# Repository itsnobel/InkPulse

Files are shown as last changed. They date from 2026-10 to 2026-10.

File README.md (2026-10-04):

# 🖊️ InkPulse — High-Speed Ultra-Low-Cost CNC XY Plotter

**InkPulse** is a custom-built, ultra-low-cost, high-speed automated XY-plotter designed to draw vector artwork and render handwritten text with extreme accuracy. Built from scratch without expensive linear bearings, this project pushes the limits of DIY hardware optimization through low-cost 3D printing and custom firmware hacking.

---

## 🌟 Key Features & Engineering Highlights

* **Ultra-Low Cost Engineering:** Replaced expensive LM8UU linear bearings with custom 3D-printed friction-based rod guides, lowering construction costs significantly compared to typical DIY plotters.
* **Firmware Register-Level Pin Remapping:** Custom **GRBL-Servo 0.9i** firmware running at **115200 Baud Rate**, remapped directly at `cpu_map_atmega328p.h` level. Y-axis pins (Step: 4, Dir: 7) were swapped with Z-axis pins (Step: 3, Dir: 6) to drive the pen lift via standard Z-slot G-code commands (`M3`/`M5`).
* **High-Speed Acceleration:** Powered by a 19V 3A DC power supply and GT2 belt-drive system, tuned to achieve up to **10,000 mm/min** maximum feed rate and **500 mm/sec²** acceleration.
* **Electrical Noise Mitigation:** Integrated a 50V 1000µF decoupling capacitor in parallel across the SG90/MG90S servo line to eliminate voltage spikes and prevent Arduino serial disconnects.

---

## 🛠️ Hardware & Components List

| Component | Description |
| :--- | :--- |
| **Controller** | Arduino Uno R3 |
| **Shield** | CNC Shield V3 |
| **Drivers** | A4988 Stepper Drivers (1/16 microstepping) |
|**Motors** | Nema 17 45Ncm stepper motor|
| **Power Supply** | 19V 3A DC Adapter |
| **Pen Lift** | SG90 / MG90S Micro Servo Motor |
| **Drive System** | GT2 Belts & 20-Tooth Pulleys |
| **Structure** | Custom 3D Printed Rod Guides + Smooth Steel Rods |
| **Power Filter**| 1000uF Electrolytic Capacitor |
|**Others**| Cooling fan, holding parts(screw, zip tie) |

---

## 📷 Photos & Video Demonstration

### Project Build & Working Demo
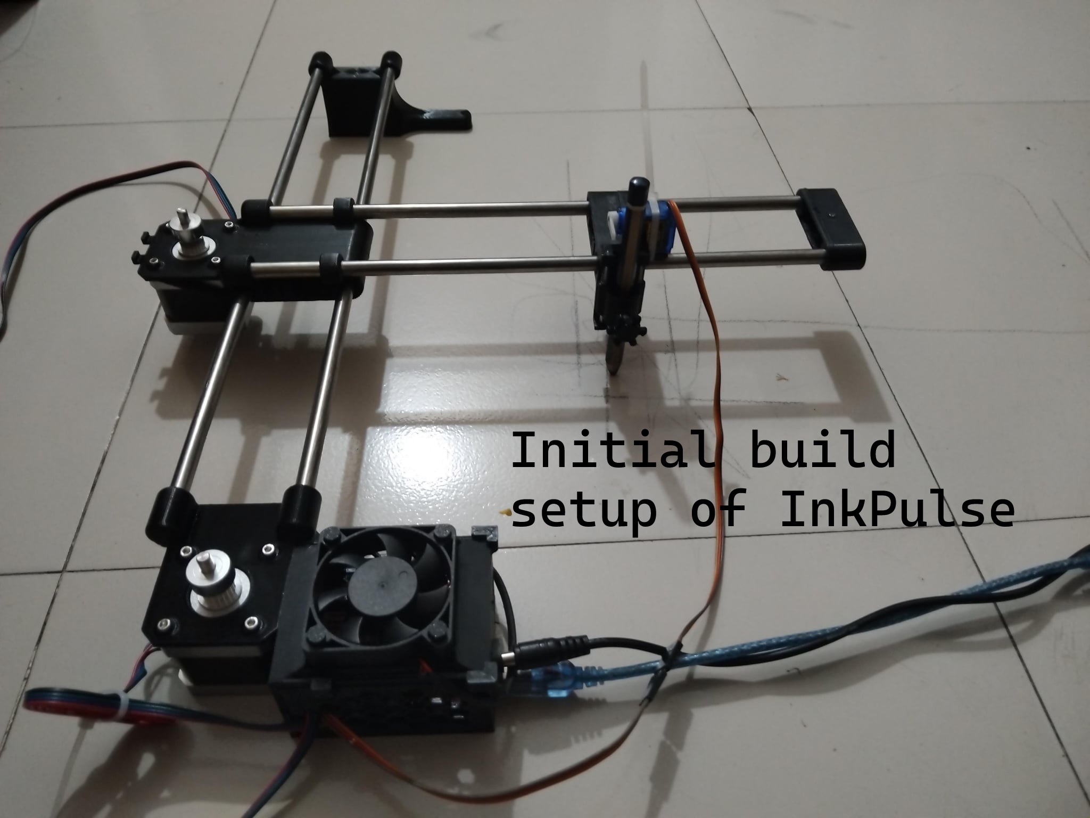
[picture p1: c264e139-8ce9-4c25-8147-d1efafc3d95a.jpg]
InkPulse Build

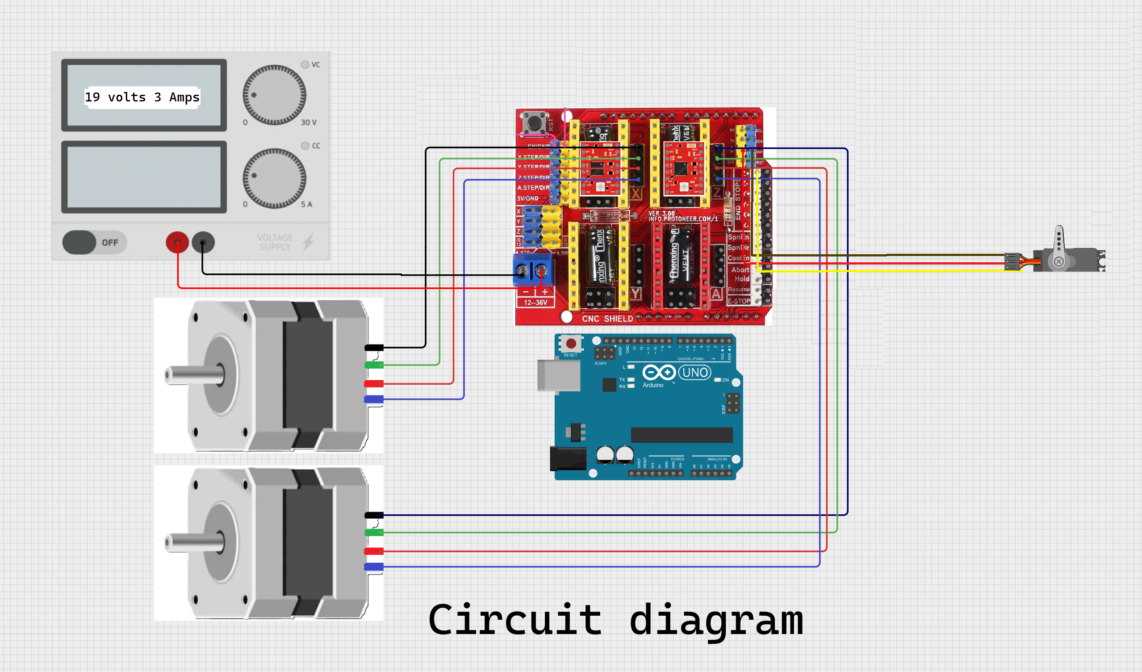
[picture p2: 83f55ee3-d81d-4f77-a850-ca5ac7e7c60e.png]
Hardware Setup

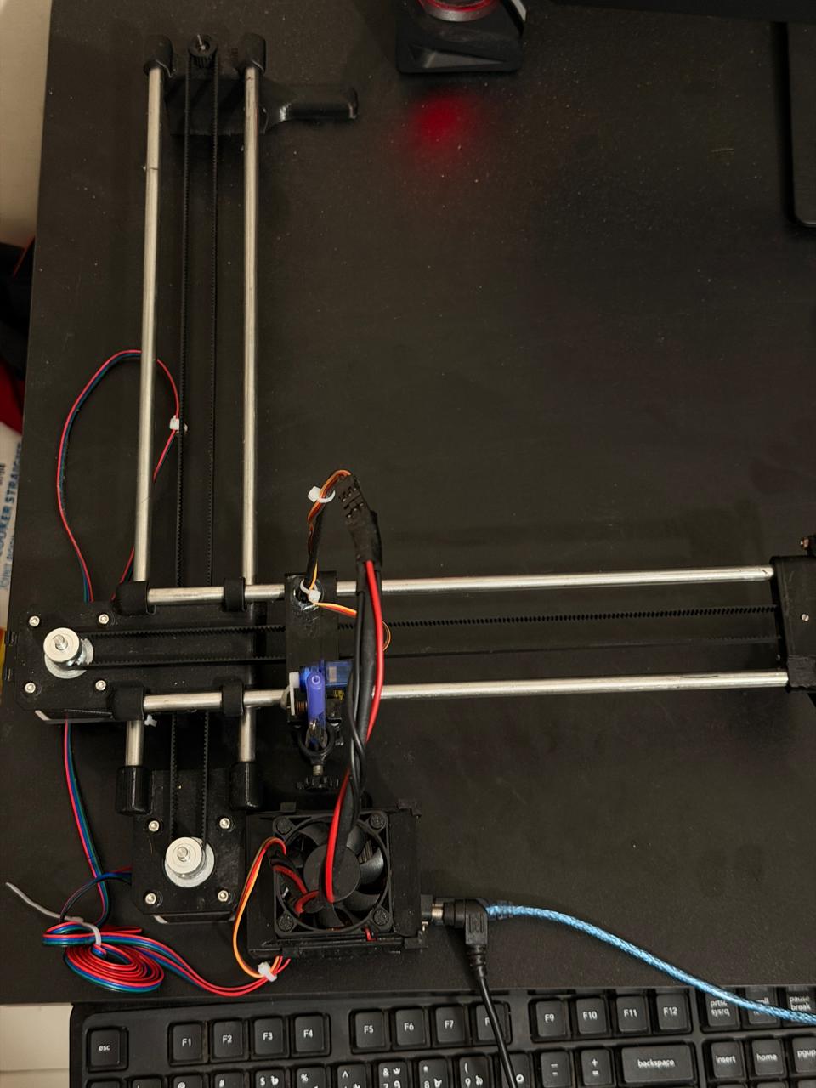
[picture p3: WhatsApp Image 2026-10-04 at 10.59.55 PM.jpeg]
Working Demonstration


🎬 **Watch Video Demo:** [Click here to view the plotter in action](WhatsApp%20Video%202026-10-04%20at%2010.53.54%20PM_squished.mp4)

---

## ⚙️️ Custom GRBL Settings

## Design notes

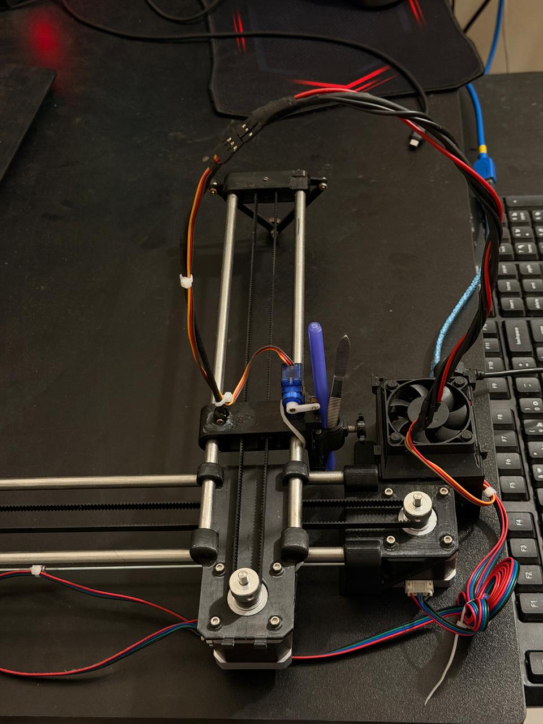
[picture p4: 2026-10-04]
9bd96195-bd8f-48d8-b6e4-d49fcb13c53a.jpg

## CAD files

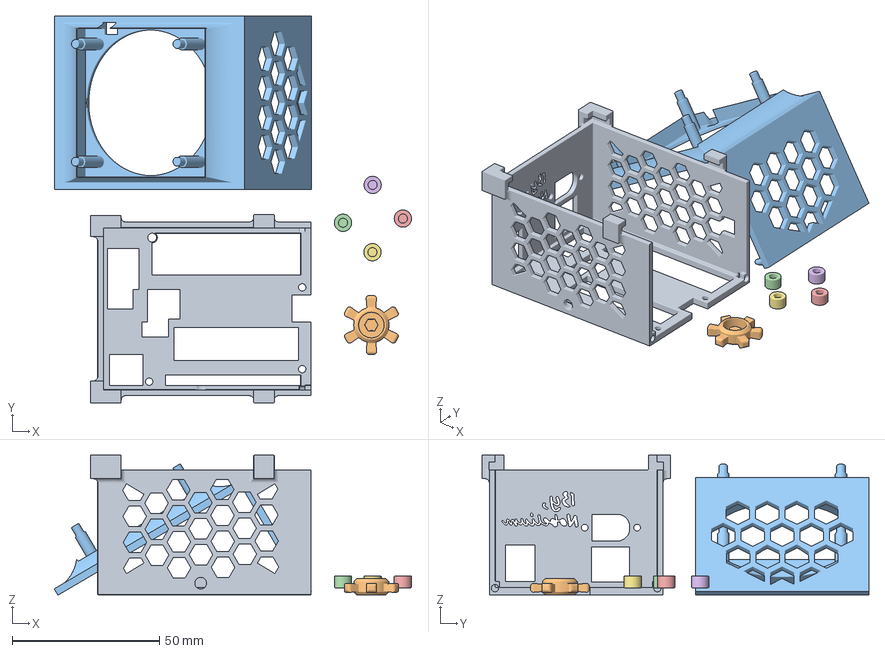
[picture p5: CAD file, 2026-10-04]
Control Unit.3mf
121.4 x 131.5 x 47.5 mm

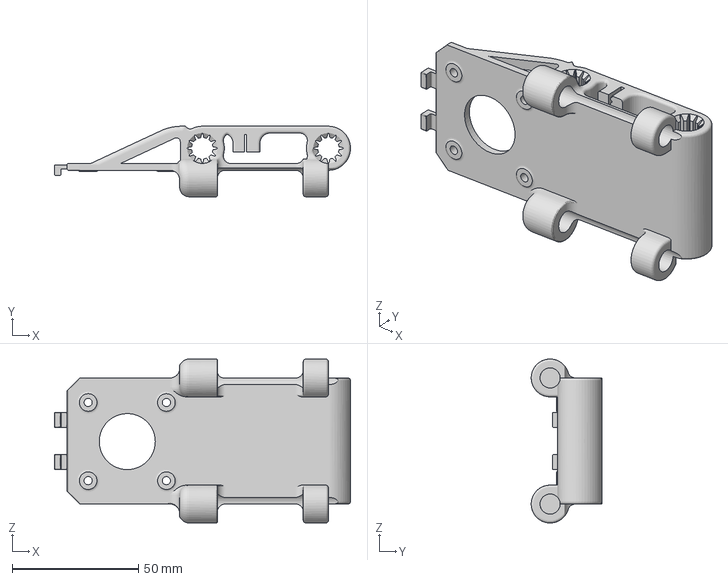
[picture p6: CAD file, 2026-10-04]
Shaft2_start.3mf
117.3 x 28.0 x 65.0 mm

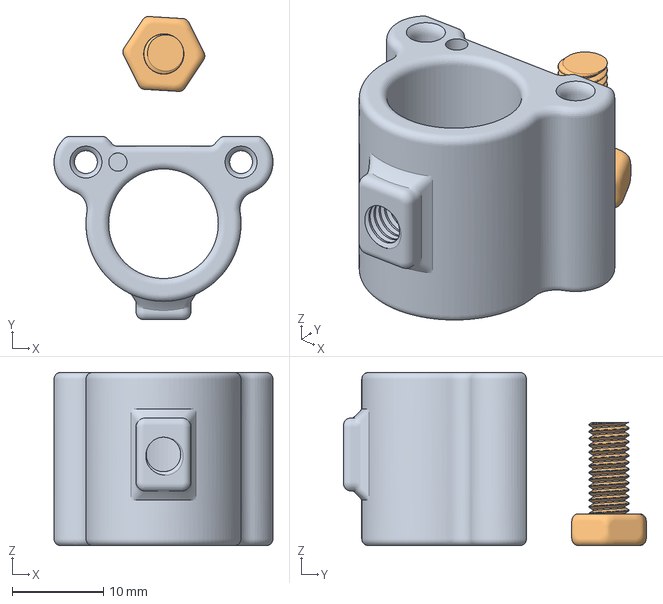
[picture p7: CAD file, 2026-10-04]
PenHolder.3mf
24.0 x 33.2 x 19.0 mm

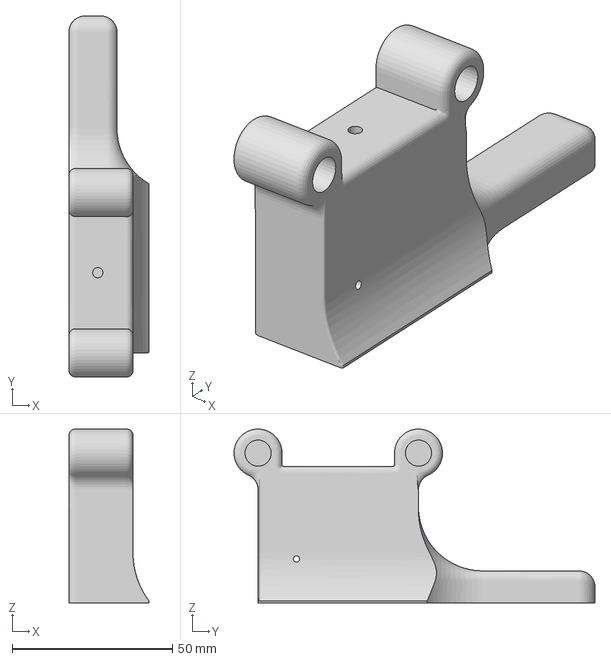
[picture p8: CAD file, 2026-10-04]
Shaft1_end.3mf
25.0 x 112.5 x 54.2 mm

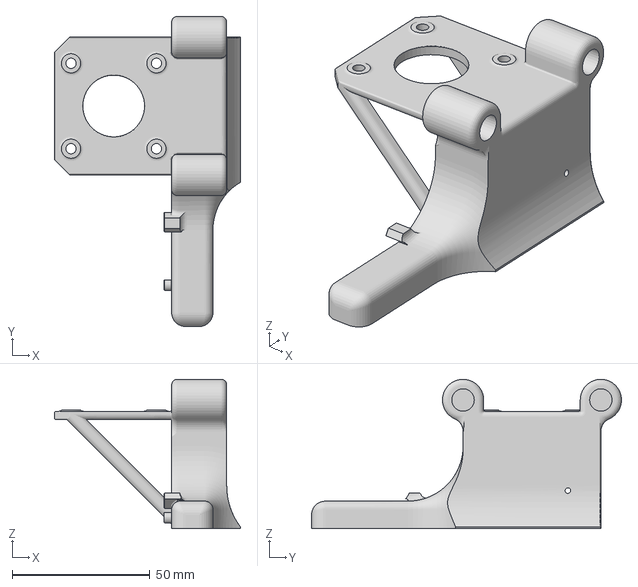
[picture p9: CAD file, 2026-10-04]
Shaft1_start.3mf
67.5 x 112.5 x 54.2 mm

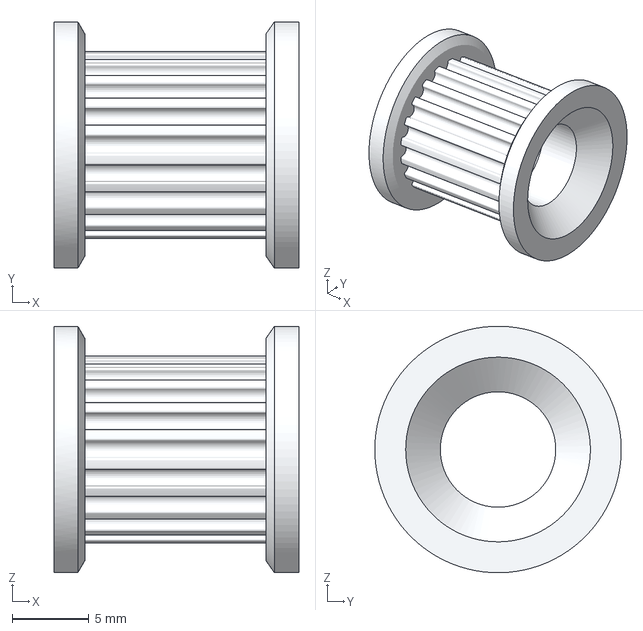
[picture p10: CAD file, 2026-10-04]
GT2_20T_Short.3mf
15.9 x 16.0 x 16.0 mm

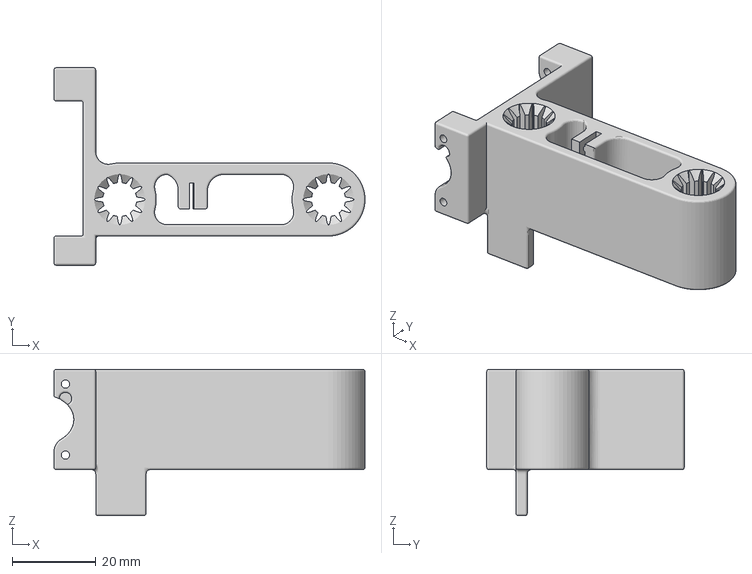
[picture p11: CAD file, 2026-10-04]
Composer.3mf
74.5 x 47.3 x 35.0 mm

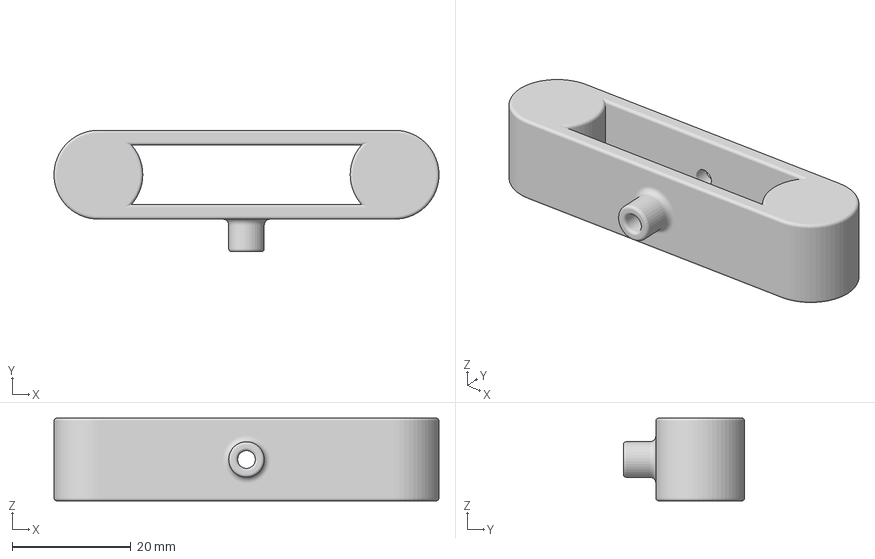
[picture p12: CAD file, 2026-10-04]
Shaft2_end.3mf
65.0 x 20.5 x 14.0 mm

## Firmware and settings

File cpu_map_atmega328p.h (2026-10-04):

/*
  cpu_map_atmega328p.h - CPU and pin mapping configuration file
  Part of Grbl

  Copyright (c) 2012-2015 Sungeun K. Jeon

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
  You should have received a copy of the GNU General Public License
  along with Grbl.  If not, see <http://www.gnu.org/licenses/>.
*/

/* Grbl officially supports the Arduino Uno, but the other supplied pin mappings are
   supplied by users, so your results may vary. This cpu_map file serves as a central
   pin mapping settings file for AVR 328p used on the Arduino Uno.  */
   
#ifdef GRBL_PLATFORM
#error "cpu_map already defined: GRBL_PLATFORM=" GRBL_PLATFORM
#endif


#define GRBL_PLATFORM "Atmega328p"

// Define serial port pins and interrupt vectors.
#define SERIAL_RX     USART_RX_vect
#define SERIAL_UDRE   USART_UDRE_vect

// Define step pulse output pins. NOTE: All step bit pins must be on the same port.
#define STEP_DDR        DDRD
#define STEP_PORT       PORTD
#define X_STEP_BIT      2  // Uno Digital Pin 2
#define Y_STEP_BIT      4  // Uno Digital Pin 3
#define Z_STEP_BIT      3  // Uno Digital Pin 4
#define STEP_MASK       ((1<<X_STEP_BIT)|(1<<Y_STEP_BIT)|(1<<Z_STEP_BIT)) // All step bits

// Define step direction output pins. NOTE: All direction pins must be on the same port.
#define DIRECTION_DDR     DDRD
#define DIRECTION_PORT    PORTD
#define X_DIRECTION_BIT   5  // Uno Digital Pin 5
#define Y_DIRECTION_BIT   7  // Uno Digital Pin 6
#define Z_DIRECTION_BIT   6  // Uno Digital Pin 7
#define DIRECTION_MASK    ((1<<X_DIRECTION_BIT)|(1<<Y_DIRECTION_BIT)|(1<<Z_DIRECTION_BIT)) // All direction bits

// Define stepper driver enable/disable output pin.
#define STEPPERS_DISABLE_DDR    DDRB
#define STEPPERS_DISABLE_PORT   PORTB
#define STEPPERS_DISABLE_BIT    0  // Uno Digital Pin 8
#define STEPPERS_DISABLE_MASK   (1<<STEPPERS_DISABLE_BIT)

// Define homing/hard limit switch input pins and limit interrupt vectors. 
// NOTE: All limit bit pins must be on the same port, but not on a port with other input pins (CONTROL).
#define LIMIT_DDR        DDRB
#define LIMIT_PIN        PINB
#define LIMIT_PORT       PORTB
#define X_LIMIT_BIT      1  // Uno Digital Pin 9
#define Y_LIMIT_BIT      2  // Uno Digital Pin 10
#ifdef VARIABLE_SPINDLE // Z Limit pin and spindle enabled swapped to access hardware PWM on Pin 11.  
  #define Z_LIMIT_BIT	   4 // Uno Digital Pin 12
#else
  #define Z_LIMIT_BIT    3  // Uno Digital Pin 11
#endif
#define LIMIT_MASK       ((1<<X_LIMIT_BIT)|(1<<Y_LIMIT_BIT)|(1<<Z_LIMIT_BIT)) // All limit bits
#define LIMIT_INT        PCIE0  // Pin change interrupt enable pin
#define LIMIT_INT_vect   PCINT0_vect 
#define LIMIT_PCMSK      PCMSK0 // Pin change interrupt register

// Define spindle enable and spindle direction output pins.
#define SPINDLE_ENABLE_DDR    DDRB
#define SPINDLE_ENABLE_PORT   PORTB
// Z Limit pin and spindle PWM/enable pin swapped to access hardware PWM on Pin 11.
#ifdef VARIABLE_SPINDLE 
  #ifdef USE_SPINDLE_DIR_AS_ENABLE_PIN
    // If enabled, spindle direction pin now used as spindle enable, while PWM remains on D11.
    #define SPINDLE_ENABLE_BIT    5  // Uno Digital Pin 13 (NOTE: D13 can't be pulled-high input due to LED.)
  #else
    #define SPINDLE_ENABLE_BIT    3  // Uno Digital Pin 11
  #endif
#else
  #define SPINDLE_ENABLE_BIT    4  // Uno Digital Pin 12
#endif
#ifndef USE_SPINDLE_DIR_AS_ENABLE_PIN
  #define SPINDLE_DIRECTION_DDR   DDRB
  #define SPINDLE_DIRECTION_PORT  PORTB
  #define SPINDLE_DIRECTION_BIT   5  // Uno Digital Pin 13 (NOTE: D13 can't be pulled-high input due to LED.)
#endif
  
// Define flood and mist coolant enable output pins.
// NOTE: Uno analog pins 4 and 5 are reserved for an i2c interface, and may be installed at
// a later date if flash and memory space allows.
#define COOLANT_FLOOD_DDR   DDRC
#define COOLANT_FLOOD_PORT  PORTC
#define COOLANT_FLOOD_BIT   3  // Uno Analog Pin 3
#ifdef ENABLE_M7 // Mist coolant disabled by default. See config.h to enable/disable.
  #define COOLANT_MIST_DDR   DDRC
  #define COOLANT_MIST_PORT  PORTC
  #define COOLANT_MIST_BIT   4 // Uno Analog Pin 4
#endif  

// Define user-control controls (cycle start, reset, feed hold) input pins.
// NOTE: All CONTROLs pins must be on the same port and not on a port with other input pins (limits).
#define CONTROL_DDR       DDRC
#define CONTROL_PIN       PINC
#define CONTROL_PORT      PORTC
#define RESET_BIT         0  // Uno Analog Pin 0
#define FEED_HOLD_BIT     1  // Uno Analog Pin 1
#define CYCLE_START_BIT   2  // Uno Analog Pin 2
#define SAFETY_DOOR_BIT   1  // Uno Analog Pin 1 NOTE: Safety door is shared with feed hold. Enabled by config define.
#define CONTROL_INT       PCIE1  // Pin change interrupt enable pin
#define CONTROL_INT_vect  PCINT1_vect
#define CONTROL_PCMSK     PCMSK1 // Pin change interrupt register
#define CONTROL_MASK ((1<<RESET_BIT)|(1<<FEED_HOLD_BIT)|(1<<CYCLE_START_BIT)|(1<<SAFETY_DOOR_BIT))
  
// Define probe switch input pin.
#define PROBE_DDR       DDRC
#define PROBE_PIN       PINC
#define PROBE_PORT      PORTC
#define PROBE_BIT       5  // Uno Analog Pin 5
#define PROBE_MASK      (1<<PROBE_BIT)

// Start of PWM & Stepper Enabled Spindle
#ifdef VARIABLE_SPINDLE
  // Advanced Configuration Below You should not need to touch these variables
  #define PWM_MAX_VALUE    255.0
  #define TCCRA_REGISTER	 TCCR2A
  #define TCCRB_REGISTER	 TCCR2B
  #define OCR_REGISTER     OCR2A
  
  #define COMB_BIT	     COM2A1
  #define WAVE0_REGISTER	 WGM20
  #define WAVE1_REGISTER	 WGM21
  #define WAVE2_REGISTER	 WGM22
  #define WAVE3_REGISTER	 WGM23
      
  // NOTE: On the 328p, these must be the same as the SPINDLE_ENABLE settings.
  #define SPINDLE_PWM_DDR	  DDRB
  #define SPINDLE_PWM_PORT  PORTB
  #define SPINDLE_PWM_BIT	  3    // Uno Digital Pin 11
#endif // End of VARIABLE_SPINDLE

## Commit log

2026-10-04 Add 3D model files and project assets
    Added custom 3D printed models (.3mf) including shaft guides, pen holder, and controller housing.
    [Composer.3mf, Control Unit.3mf, GT2_20T_Short.3mf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]
2026-10-04 Add motors and others sections to README
2026-10-28 Define pin mappings for Atmega328p GRBL platform
    Added definitions for various control and output pins for GRBL platform.

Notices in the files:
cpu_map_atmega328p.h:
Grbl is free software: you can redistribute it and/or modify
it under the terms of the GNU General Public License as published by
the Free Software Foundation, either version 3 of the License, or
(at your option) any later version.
